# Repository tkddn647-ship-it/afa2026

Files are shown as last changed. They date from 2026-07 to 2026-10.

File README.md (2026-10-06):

# AFA2026 계측 시스템

학생 포뮬러 전기차(아주대학교 A-FA)의 **실차 데이터 계측 시스템**입니다.
서스펜션·가속도·인버터/BMS·조향 데이터를 STM32 한 곳에서 같은 시간축으로 모으고, Raspberry Pi를 거쳐 서버에 기록·실시간 표시·카메라 녹화까지 연결합니다.

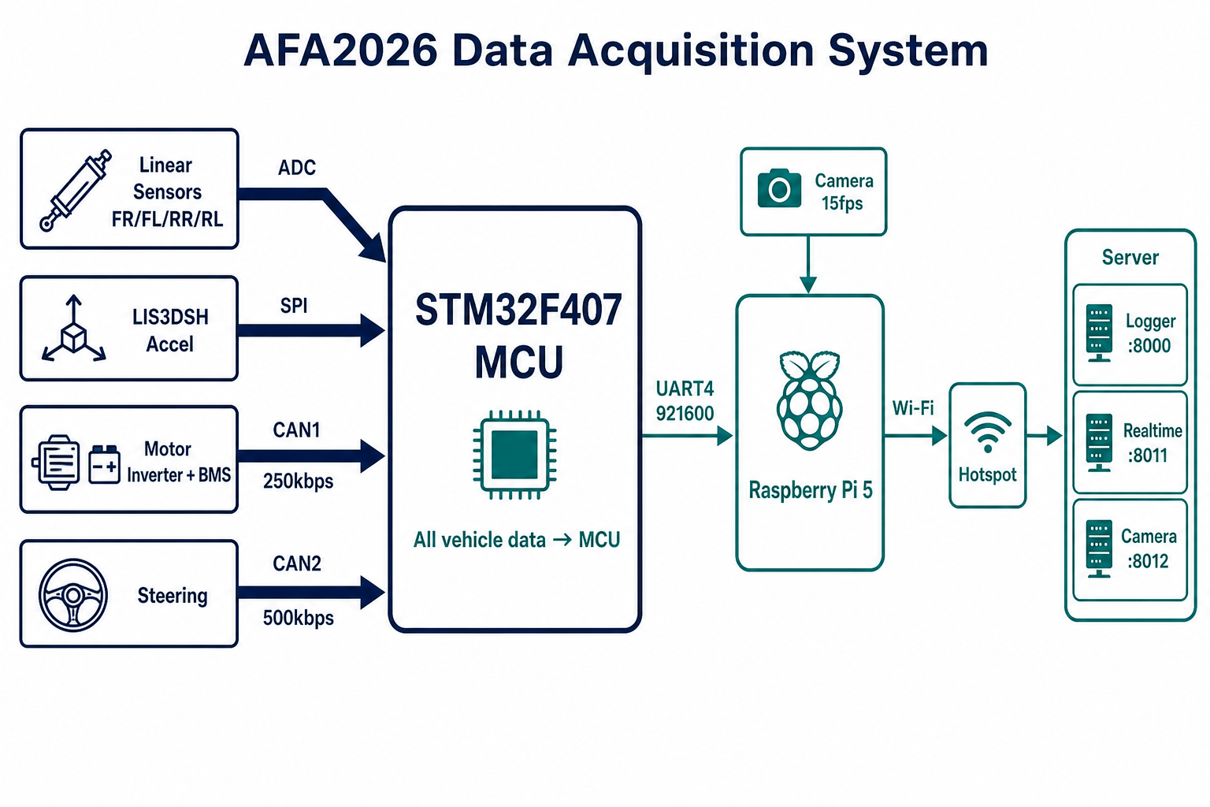
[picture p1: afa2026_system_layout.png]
AFA2026 Data Acquisition System


| 항목 | 내용 |
|---|---|
| 기간 | 2025.09 ~ 2026.08 |
| 역할 | 계측 파트장 (계측 파트 2인) |
| 하드웨어 | STM32F407, Raspberry Pi 5, Cascadia 인버터 · Orion BMS 2 · Bosch LWS (CAN) |
| 소프트웨어 | C (STM32 HAL, DMA), Python (FastAPI 서버, 분석), JavaScript (대시보드) |

## 주요 결과

| 항목 | 결과 |
|---|---|
| 데이터 운용 주기 | 전송 방식을 WebSocket → UDP/TCP로 바꾸고 MCU에 링버퍼 + DMA 적용, **10 Hz → 100 Hz** |
| 신호 오류 판정 | 실주행 로그 3개(74,062행)에서 인버터 DC 전류가 팩 전류보다 약 25% 크게 기록된 것을 발견, 비율 0.80 재현으로 **CAN 스케일 계수 누락** 규명, 보정 계수 1.25 도출 |
| 계측 정확도 | 섀시 다이나모 교차 검증: 최고속도 계측 90 km/h vs 다이나모 87 km/h (**오차 약 3.4%**) |
| EMI 대응 | HV 동작 시 튀는 센서 값을 HV ON/OFF 시점 대조로 전자기 간섭으로 규명, 신호선 분리 · 차폐로 해결 |
| 분석 도구 | 주행 로그와 카메라 영상을 같은 시간축으로 맞춰 보는 도구를 만들어 섀시 · 파워트레인 파트가 주행 분석에 사용 |

## 남은 과제

- **데이터 무결성**: 로그별 샘플 누락 5~10%, 깨진 행 최대 약 0.1% → 바이너리 패킷 + CRC + 시퀀스 번호로 수신 즉시 판별
- **절대값 검증**: 두 전류의 비율은 맞췄지만 어느 쪽이 절대적으로 정확한지는 미검증 → 클램프 미터로 독립 측정
- **보안**: 팀 내부 전용이라 성능을 우선했음 → 열린 포트 최소화, SSH 키 인증, 방화벽 적용
- 펌웨어 RTOS 전환, 리니어 센서 전원 강하 원인 특정 (아래 §11, §4.2)

## 저장소 구성

| 경로 | 내용 |
|---|---|
| `device/ECU_test/` | STM32CubeIDE 프로젝트 (메인 MCU 펌웨어) |
| `device/raspberry pi 5/` | UART 수신 · 서버 전송 · 카메라 업로드 |
| `server/` | 로깅(`udp_logger`), 실시간 대시보드(`udp_realtime`), 분석 서버(`analysis_server`) |
| `hardware/26_TELEPCB/` | 텔레메트리 보드 KiCad 회로도 · PCB · 거버 |

아래부터는 다음 담당자를 위한 **설계 의도와 구현 구조** 문서입니다.

---

## 1. 한 줄 요약

> 차량의 리니어·가속도·인버터/BMS·조향 데이터를 **MCU에서 동일 타임라인으로 통합 수집(100 Hz)** 하고, UART로 Raspberry Pi에 넘겨 Hotspot Wi‑Fi로 서버에 로깅·실시간 표시·카메라 녹화까지 연결한다.  
> (현재 구현 보드는 STM32F407이며, **시간 동기화가 목적이라 Teensy 등 다른 MCU로 대체 가능** — 자세한 내용은 §5.2)

---

## 2. 전체 시스템 구조

```
[차량 센서/ECU들]                    [현장 보드]                         [네트워크]         [서버]
Linear FR/FL/RR/RL ──ADC──┐
LIS3DSH Accel ──────SPI───┤
Motor Inverter+BMS ─CAN1──┼──▶ STM32F407 MCU ──UART4 921600──▶ Raspberry Pi 5 ──Wi‑Fi──▶ Hotspot
Steering (LWS) ─────CAN2──┘         ▲                              │ Camera 15fps              │
Wheel speed (옵션) ─USART2─┘         │                              │                           ▼
                                      │                         data_send_server.py     Logger   :8000
                                      └─ 모든 텔레메트리 1차 집약                         Realtime :8011
                                                                                         Camera   :8012
```

설계의 핵심은 **“모든 차량 데이터는 먼저 MCU로 모인다”** 입니다.

| 구간 | 역할 |
|---|---|
| 센서 / CAN | 물리량·차량 버스 데이터 생성 |
| **STM32 MCU** | 샘플링·단위 환산·버퍼링·동기 타임스탬프 |
| **UART4** | MCU → Pi 단일 CSV 스트림 |
| **Raspberry Pi 5** | 파싱, 배치 HTTP 전송, 카메라 프레임 업로드 |
| **Hotspot** | 이동 환경 Wi‑Fi (아이폰 핫스팟 등으로 운용) |
| **서버** | 집 노트북에서 구동. CSV 로깅, 실시간 대시보드, 카메라 수신/녹화. 공유기 포트포워딩 + SSH로 원격 관리 |

배치도 이미지: [`afa2026_system_layout.png`](./afa2026_system_layout.png)

서버는 클라우드 전용 VM이 아니라 **집에 둔 노트북**을 서버로 쓰고, 공유기·방화벽·SSH를 열어 **밖에서도 본인 PC로 원격 접속·제어**하는 방식으로 운용했습니다. 자세한 절차는 [§8. 집 서버 원격 접속 (포트포워딩 + SSH)](#8-집-서버-원격-접속-포트포워딩--ssh) 참고.

---

## 3. 하드웨어 설계

### 3.1 MCU 보드

| 항목 | 내용 |
|---|---|
| MCU | **STM32F407** (Discovery / 커스텀 PCB 연동) |
| 클럭 | HSE 크리스털 → PLL (시스템 클럭). UART/CAN 비트 타이밍 정확도에 필요 |
| 워치독 | IWDG (~1 s) — 메인 루프 정지 시 리셋 |

### 3.2 센서·버스 핀맵 (펌웨어 기준)

#### 리니어 포텐셔미터 (서스펜션 변위)

| 채널 | MCU 핀 | ADC | 비고 |
|---|---|-----|---|
| **FR** | PA1 | ADC1_IN1 | 3선: VCC / GND / Signal |
| **RR** | PA2 | ADC1_IN2 | |
| **RL** | PA3 | ADC1_IN3 | |
| **FL** | PA4 | ADC1_IN4 | |

- ADC 기준(VDDA)은 **3.3 V**
- 센서 공급/풀스케일 전압은 채널별로 다르며, **소프트웨어 vmax 캘리브레이션**으로 0–100 mm에 맞춤
- Discovery **PA0**은 유저 버튼용이라 리니어에 사용하지 않음

#### 가속도

| 센서 | 인터페이스 | 비고 |
|---|---|---|
| LIS3DSH | SPI1 | ODR 상향(400 Hz급)으로 200/100 Hz 샘플에 대응 |

#### CAN

| 버스 | 속도 | 핀 (펌웨어) | 상대 |
|---|---|---|---|
| **CAN1** | 250 kbps | **PB8 RX / PB9 TX** | Cascadia 인버터 + Orion BMS |
| **CAN2** | 500 kbps | **PB12 / PB13** | Bosch LWS 조향 |

> 회로도/PCB와 핀이 어긋나면(예: CAN1이 PA11/PA12로만 배선) 수신이 안 됩니다. 펌웨어는 **PB8/PB9, PB12/PB13** 기준입니다.

#### UART

| 포트 | 보드레이트 | 핀 | 용도 |
|---|---|-----|---|
| **UART4** | **921600** | PC10 TX / PC11 RX | Raspberry Pi 텔레메트리 |
| USART2 | 115200 | (휠스피드 아두이노 등) | 옵션 |

Pi 배선 (GPIO):

| STM32 | Raspberry Pi 5 |
|---|---|
| PC10 (UART4 TX) | Pin 10 (GPIO15 RX) |
| PC11 (UART4 RX) | Pin 8 (GPIO14 TX) |
| GND | GND |

포트: `/dev/ttyAMA0` (`dtparam=uart0=on`)

### 3.3 전원·배치·실차 이슈 (설계 시 고려)

- MCU·Pi는 근거리(배전함 등)에 두고, 모터컨트롤러는 함 밖인 경우가 많음 → **UART 거리는 짧아 유리**, 다만 **고전류 GND/EMI**가 케이블로 타고 들어옴
- 리니어 케이블에서 **신호↔파워 교차/단락** 시 중간 위치에서도 ADC가 ~3.3 V(100 mm 고정)처럼 보임 → 하드웨어 배선 문제로 확인됨
- 플로팅 ADC 핀은 센서 미연결 시에도 중간값이 움직임 → 정상 현상
- 핫스팟 + 차량 이동 시 **Pi→서버 업로드**가 병목이 되어 로그 유효 Hz가 떨어질 수 있음 (MCU 샘플링과 별개)

---

## 4. 소프트웨어 아키텍처 (device)

### 4.1 디렉터리

```
device/
├── ECU_test/                 # STM32CubeIDE 프로젝트 (메인 MCU 펌웨어)
│   ├── Core/Inc|Src/         # 애플리케이션 코드
│   ├── Drivers/              # HAL / CMSIS
│   └── ECU_test.ioc          # CubeMX 설정
├── raspberry pi 5/           # Pi 수신·서버 전송·카메라
│   ├── Uart_stm.py           # UART CSV 파서
│   ├── data_send_server.py   # ingest / realtime 전송
│   ├── camera.py             # 카메라 프레임 업로드 (15fps 운용)
│   └── stm_ingest.env.example
├── wheel_speed/              # 휠스피드 아두이노 (옵션)
├── Fluid_Sensor/             # 유체 센서 스케치
├── esp32/ , esp32_motor_can/ # 보조/실험용
└── ...
```

### 4.2 STM32 펌웨어 — 슈퍼루프 설계

RTOS 없이 **메인 루프 + 논블로킹** 구조입니다 (`main.c`).

1. `MX_*_Init` — GPIO, CAN1/2, UART, ADC, SPI, DMA
2. `LIS3DSH` / `CAN_Vehicle` / `CAN_LWS` / `SensorUart` / `Uart4Tx` 초기화
3. 루프:
   - CAN FIFO 드레인·파싱
   - `SensorUart_Process()` — 100 Hz 샘플 적재, 20 Hz DMA flush
   - IWDG kick

#### 샘플링 / 전송

| 항목 | 값 | 파일 |
|---|-----|---|
| 샘플 주기 | **10 ms (100 Hz)** | `sensor_uart.h` / `.c` |
| UART flush | **20 Hz**, 배치 5샘플 | 동일 |
| TX | UART4 **DMA 논블로킹** | `uart4_tx.c` |
| Baud | **921600** | `usart.c` |

초기에는 200 Hz(5 ms)였으나, 실차·무선 부하를 고려해 **100 Hz**로 조정했습니다.

#### 리니어 ADC 처리 (`adc.c` / `adc.h`)

1. 채널당 **8회 평균**
2. **EMA** 필터 (노이즈 완화)
3. 전압 환산: `voltage_mv = raw × 3300 / 4095`
4. 위치 환산(채널별):

```text
position_mm = (voltage_mv / ADC_LINEAR_VMAX_xx_MV) × 100
```

풀 스트로크 실측으로 vmax를 맞춥니다. (예: 풀에서 88.6 mm가 나오면 `vmax_new = vmax_old × 0.886`)

최신 캘리 상수 예:

| 채널 | `ADC_LINEAR_VMAX_*_MV` |
|---|---|
| FR | 1825 |
| RR | 1835 |
| RL | 1827 |
| FL | 1818 |

미해결 이슈 — ADC형 센서 전원 강하 원인 규명 필요: 리니어 포텐셔미터 전원부에서 3A 레귤레이터 Vout 자체는 3.3V로 정상이었으나, PCB를 지나 센서 커넥터 단에서는 2.3~2.7V까지 떨어지는 현상이 실측됐습니다. 흐르는 전류가 mA 수준(저항 분압 구조)인 점을 감안하면 컨버터 용량 부족은 아니며, Vout 이후 구간(PCB 파워 트레이스 또는 커넥터 접점)에서 비정상적으로 큰 저항이 있는 것으로 추정되는데 이게 어디가 문제인지 정확하게 확인을 못해서 소프트웨어적으로 캘리브레이션 우선 했습니다. 이 전압 강하가 vmax 캘리브레이션을 흔드는 원인이 될 수 있어, 트레이스 문제인지 커넥터 접점 문제인지 다음 담당자가 실측으로 특정해야 하는 미해결 문제입니다.

#### CAN 파싱 (`can_vehicle.c`, `can_lws.c`)

- Cascadia Motion 프로토콜(V5.9 계열): 온도·전류·전압·토크·Id/Iq·RPM 등 **int16 × 0.1** 환산 후 float 보관
- Orion BMS 커스텀 ID(0x081/0x082 등): 전압·전류·Ah·온도·CCL/DCL
- LWS: 조향각·조향 속도
- UART로 나가기 전에 **이미 공학 단위로 환산**됨 (Pi/서버에서 재스케일하지 않음)
- `can1` / `can2`: 최근 **500 ms** 내 수신 여부 (0/1)

#### UART CSV 한 줄 (순서 고정)

```text
stm_ms, FR, FL, RR, RL, x_g, y_g, z_g, ecu_temp,
steering_angle, steering_speed,
inv_temp_igt, inv_temp_motor, inv_motor_speed, inv_dc_current, inv_voltage,
motor_precharge, motor_main_contactor, motor_inverter_mode,
inv_shudder_torque, inv_id_feedback, inv_iq_feedback,
inv_torque_commanded, inv_torque_feedback, inv_id_command, inv_iq_command,
bms_charge, bms_voltage, bms_current, bms_ccl, bms_dcl, bms_temp_maxvalue, bms_capacity,
can1, can2
```

제어 라인(데이터 아님): `STM_READY`, `HB,...`, `LWS_CAL,...`

차속은 `inv_motor_speed × 0.0222328` (타이어 외경 460 mm, 감속비 3.9)로 **서버/Pi에서 계산**하는 것을 권장 (UART 필드 추가 불필요).

### 4.3 Raspberry Pi 5

| 스크립트 | 역할 |
|---|---|
| `Uart_stm.py` | 921600 수신, CSV 파싱, 100 Hz/20 Hz 배치 개념 |
| `data_send_server.py` | 배치를 Logger `:8000/ingest` + (옵션) Realtime `:8011` 로 POST |
| `camera.py` | JPEG 프레임 업로드 (운용 **15 fps**) |
| `uart_test.py` | 보드레이트/배선 점검 |

예시:

```bash
python3 data_send_server.py \
  --port /dev/ttyAMA0 \
  --baud 921600 \
  --realtime-url http://<server>:8011/api/live/ingest
```

환경 변수 예시는 `stm_ingest.env.example` 참고.

### 4.4 서버 쪽 (연동만 요약)

| 서비스 | 포트 | 역할 |
|---|---|---|
| `udp_logger` | 8000 | CSV 로깅 ingest |
| `udp_realtime` | 8011 | 실시간 대시보드 |
| camera | 8012 | 프레임 수신·녹화(ffmpeg) |

실차에서 로그 유효 Hz가 50대까지 떨어지는 경우, CSV의 `stm_ms`는 대부분 10 ms를 유지하는 반면 wall-clock 초당 행 수만 줄어든 패턴이 많았습니다 → **MCU 샘플링보다 Hotspot/서버 업로드·카메라 부하**가 원인인 경우가 많습니다. 센서 100 Hz를 유지하려면 카메라 fps/해상도를 먼저 낮추는 편이 유리합니다.

---

## 5. 핵심 설계 판단

### 5.1 MCU 중앙 통합 — 핵심은 “시간 동기화”

이 프로젝트에서 MCU(현재 구현은 STM32F407)를 둔 **가장 큰 이유**는 브랜드가 아니라 **시간 동기화**입니다.

- 리니어·가속도·인버터/BMS CAN·조향 CAN을 **서로 다른 장치·주기**로 받으면, 나중에 맞춰도 샘플 시각이 어긋나기 쉽습니다.
- 그래서 **한 MCU의 틱(`stm_ms` / `HAL_GetTick` 계열)으로 모든 채널을 같은 타임라인에 찍어** Pi·서버로 넘기는 구조를 택했습니다.
- Pi는 네트워크·카메라·업로드를 담당하고, **정밀 주기 샘플링·CAN 집약은 MCU**에 두는 역할 분리입니다.

| | 내용 |
|--|---|
| **선택 이유** | 서스펜션·구동·조향을 **동일 타임스탬프**로 맞춤 |
| **장점** | 단일 UART 스트림, 디버그·확장 용이, 실차 EMI 환경에서도 샘플 주기를 MCU가 책임 |
| **리스크** | MCU/UART가 단일 장애점, CSV가 길면 UART·무선 부하 증가 |

### 5.2 STM32를 꼭 고집할 필요는 없음

**“STM이어야만 한다”는 제약은 없습니다.**  
필요한 것은 대략 다음을 만족하는 **실시간 MCU**면 됩니다.

- ADC(리니어) + (가능하면) SPI/I2C 센서
- CAN 1~2채널 (인버터/BMS/조향)
- 안정적인 주기 타이머·타임스탬프
- Pi로 넘길 UART(또는 USB serial 등) 고속 스트림

그래서 예를 들면 아래도 **같은 역할의 중앙 계측 MCU**로 대체·재구현 가능합니다.

| 후보 | 메모 |
|---|---|
| **Teensy** (4.x 등) | 고속 클럭, USB/시리얼 편함, 커뮤니티 센서 예제 많음 |
| **다른 STM32** | 핀맵·Cube 설정만 맞으면 현재 구조와 가장 유사 |
| **ESP32** 계열 | Wi‑Fi 내장이라 Pi를 줄이는 실험도 가능하나, CAN·실시간·EMI는 설계 부담이 달라짐 |
| **기타 Cortex‑M / 보드** | ADC+CAN+UART만 되면 파이프라인 개념은 동일 |

지금 저장소 펌웨어는 **STM32F407 Discovery/Cube 기반**으로 작성된 **한 가지 구현**입니다.  
구조(센서·CAN → MCU 타임라인 → 시리얼 → Pi → 서버)만 유지하면 **Teensy 등 다른 MCU로 포팅해도 설계 의도는 그대로**입니다.

### 5.3 대안이었던 분산 전송

- 센서·카메라를 각자 올리거나 주기만 다르게 하는 방식
- 무선 부하는 나눌 수 있으나 **시각 동기·배선·프로토콜 복잡도**가 커짐 → 본 프로젝트 목표(동기 로깅)와는 덜 맞음

### 5.4 샘플링 100 Hz / UART 921600

- 200 Hz → 100 Hz: 루프·UART·업로드 여유
- 460800 ↔ 921600: 용량 vs EMI/배선 안정성 트레이드오프. 근거리면 921600 가능

### 5.5 리니어 캘리브레이션을 소프트웨어로

- 채널마다 풀전압이 다름 (하드웨어·케이블·장착)
- 코드에서 채널별 `vmax`로 100 mm 맞춤 — **배선 불량(신호/파워 교차)은 캘리로 고칠 수 없음**

### 5.6 텔레메트리 전송 방식의 다른 선택지

계측에서 “차 → 기록 PC/서버”로 데이터를 넘기는 방법은 팀이 제각각이라, **이 저장소 방식(MCU + Pi + Hotspot Wi‑Fi)이 유일한 정답은 아닙니다.**  
크게 보면 아래 세 갈래로 나뉩니다.

#### (A) 상용 데이터로거를 사서 쓰는 경우

- 완성품 로거에 센서/CAN을 꽂고 USB·자체 소프트웨어로 기록
- **장점:** 배선·펌웨어·동기 UI가 제품에 포함되어 있어 구현 부담이 작음
- **단점:** 가격, 커스텀 필드/서버 연동·실시간 웹 파이프라인은 제품 제약을 따름
- DIY 계측을 깊게 파고든 팀을 찾기 어려운 이유 중 하나가, **많은 팀이 이 경로로 가기 때문**입니다. 상용 로거 사용 자체는 문제 없고, 다만 **자작 MCU 파이프라인 노하우를 물어볼 상대는 상대적으로 적습니다.**

#### (B) 본 프로젝트 — MCU 집약 + Pi + Hotspot(Wi‑Fi/인터넷)

- MCU가 동기 샘플 → UART → Pi → Hotspot → 집 서버
- **장점:** 필드·서버·카메라를 자유롭게 확장, 비용 대비 커스터마이즈
- **단점:** 무선은 Hotspot/공유기 품질에 민감, 직접 디버깅·보안·전원 설계가 필요

#### (C) UART형 장거리 무선 모듈 — 예: **EBYTE E220-900T22S**

일부 팀은 Wi‑Fi/휴대폰 핫스팟 대신, MCU(또는 중간 보드)의 **UART에 LoRa 계열 무선 시리얼 모듈**을 달아 송수신합니다.

| 항목 | E220-900T22S 요약 ([Ebyte 제품 페이지](https://www.cdebyte.com/products/E220-900T22S)) |
|---|---|
| 종류 | LoRa 기반 **무선 시리얼(UART) 모듈** (LLCC68) |
| 주파수 | 약 **850.125 ~ 930.125 MHz** (기본 예: 873.125 MHz, 868/915 MHz 대역 운용) |
| 출력 | 최대 **22 dBm** |
| 공칭 거리 | 개활지 기준 **수 km**급 (안테나·속도·환경에 크게 좌우) |
| 공중 전송률 | 대략 **2.4 kbps ~ 62.5 kbps** (설정에 따라) — **Wi‑Fi보다 훨씬 느림** |
| 인터페이스 | TTL UART (3.3 V 로직), MCU 시리얼에 붙이는 형태 |

**어떻게 쓰이나 (개념):**

```text
[차량 MCU] --UART--> [E220 송신]  ~~~900MHz LoRa~~~  [E220 수신] --UART--> [기록 PC / 다른 MCU]
```

- Hotspot·공유기·인터넷 없이도 **차 ↔ 피트/노트북** 직통에 가깝게 쓸 수 있는 선택지
- 다만 공중 속도가 낮아 **본 프로젝트처럼 긴 CSV를 100 Hz로 풀 스트리밍**하기엔 대역이 부족할 수 있음  
  → 보통은 **샘플 주기·필드 축소, 배치/압축, 또는 로컬 SD에 풀레이트 저장 + 무선은 요약/저속** 같은 설계가 필요
- 주파수·출력은 **해당 국가 전파 규정**을 반드시 확인할 것 (무단 고출력·비허가 대역 사용 금지)

본 저장소는 **(B) Wi‑Fi/Hotspot 경로를 구현·문서화**한 것이며, **(C) E220-900T22S 같은 UART LoRa 모듈 통신도 업계·동계에서 쓰이는 다른 갈래**라는 점만 참고용으로 남깁니다.  
이 레포에 E220 드라이버/설정 코드는 포함되어 있지 않습니다.

---

## 6. 디버그 체크리스트

### STM Live Expressions 예

```text
adc_linear_readings[0..3]   // FR,RR,RL,FL
adc_debug_raw[i]
g_can_vehicle_state.rx_total
g_lws_state.rx_count
uart4_tx_overflow
sensor_uart_overflow
main_loop_count
```

### 증상별

| 증상 | 우선 의심 |
|---|---|
| ADC만 나오고 CAN 0 | CAN 배선/트랜시버/핀맵, `can1`/`can2` |
| 중간인데 리니어 100 고정, raw≈4095 | 신호선–VCC 단락/교차 |
| 미연결 채널 값이 튐 | 플로팅 핀 (정상) |
| 로그 Hz만 떨어짐, `stm_ms`는 ~10 ms | Pi→서버 Wi‑Fi / 카메라 부하 |
| -553 mm 등 이상값 다수 | UART 줄 깨짐·컬럼 밀림 |

---

## 7. 빌드·플래시·실행

### STM32

1. STM32CubeIDE에서 `device/ECU_test` 오픈
2. Build → Debug/Run으로 보드에 플래시
3. UART4 921600, CAN 핀맵이 배선과 일치하는지 확인

### Raspberry Pi

```bash
cd "device/raspberry pi 5"
pip install pyserial requests
python3 data_send_server.py --port /dev/ttyAMA0 --baud 921600
```

카메라:

```bash
python3 camera.py --fps 15
```

---

## 8. 집 서버 원격 접속 (포트포워딩 + SSH)

계측 서버(`udp_logger` / `udp_realtime` / camera 등)는 **집 PC(노트북)** 에서 돌리고, 현장(차·Pi)은 Hotspot Wi‑Fi로 그 서버에 데이터를 올립니다.  
서버 노트북은 항상 옆에 둘 수 없으므로, **집 공유기 포트포워딩 + OS 방화벽에서 SSH(22) 허용**해 두고, 밖에서는 **공인 IP 또는 DDNS 도메인**으로 SSH 접속해 노트북을 원격 제어했습니다.

### 8.1 전체 흐름

```text
[밖: 본인 노트북 / 폰]
        │  ssh user@<공인IP또는도메인> -p 22
        ▼
[인터넷]
        ▼
[집 공유기]  ── 포트포워딩: 외부 22 → 서버노트북 사설IP:22
        │         (필요 시 8000/8011/8012 등 HTTP도 포워딩)
        ▼
[서버 노트북]  OpenSSH 서버 수신
        │
        ├─ 터미널로 서비스 재시작, 로그 확인, 코드 pull …
        └─ (터널/브라우저) 로거·실시간 페이지 점검
```

즉 **“서버 = 집 노트북”** 이고, **“원격 = SSH로 그 노트북에 들어가 조작”** 입니다.

### 8.2 서버 노트북 준비 (SSH 서버)

1. OS에 **OpenSSH Server** 설치·활성화  
   - Linux: `openssh-server` 설치 후 `sshd` 기동  
   - Windows: 선택적 기능에서 OpenSSH 서버 사용 가능
2. 로그인할 **계정/비밀번호 또는 SSH 키** 준비 (키 인증 권장)
3. 노트북이 절전으로 네트워크가 끊기지 않게 **절전/디스플레이 끄기 설정** 조정
4. 가능하면 공유기 DHCP에서 서버 PC에 **고정 사설 IP** (예: `192.168.0.50`) 예약

접속 예:

```bash
ssh <username>@<공인IP또는도메인>
# 포트가 22가 아니면
ssh -p <포트> <username>@<공인IP또는도메인>
```

접속되면 집 노트북 셸이 열리고, 여기서 `server/` 서비스 기동·재시작·로그 확인 등 **원격으로 서버를 조종**할 수 있습니다.

### 8.3 OS 방화벽 — 22번(SSH) 허용

노트북 방화벽에서 **인바운드 TCP 22** 를 허용해야 공유기까지 들어온 SSH가 PC에 도달합니다.

- Linux (`ufw` 예): `sudo ufw allow 22/tcp` 후 `sudo ufw enable`
- Windows: Windows Defender 방화벽 → 인바운드 규칙에서 OpenSSH(또는 TCP 22) 허용

계측 HTTP도 밖에서도 열려야 하면 동일하게 **8000 / 8011 / 8012** 등을 허용합니다.  
(현장 Pi → 서버만 쓰고, 본인은 SSH만 쓸 계획이면 HTTP는 LAN 전용으로 두고 SSH 터널로만 볼 수도 있습니다.)

### 8.4 집 공유기 포트포워딩

공유기 관리 페이지(보통 `192.168.0.1` / `192.168.1.1`)에서:

| 항목 | 설정 예 |
|---|---|
| 서비스 이름 | SSH |
| 외부(WAN) 포트 | **22** (또는 보안상 다른 포트로 바꿔 내부 22로 변환) |
| 내부 IP | 서버 노트북 사설 IP |
| 내부 포트 | **22** |
| 프로토콜 | TCP |

추가로 로거/실시간/카메라를 외부에서 직접 열려면:

| 외부 포트 | 내부 | 용도 |
|---|---|---|
| 8000 | 노트북:8000 | Logger ingest / CSV |
| 8011 | 노트북:8011 | Realtime |
| 8012 | 노트북:8012 | Camera |

Pi의 `--url` / `--realtime-url` 에는 **공유기 공인 IP 또는 DDNS 도메인**을 넣습니다.  
예: `http://<your-domain>.ddns.net:8000/ingest`

### 8.5 공인 IP vs 도메인 (DDNS)

- **고정 공인 IP**면 IP로 바로 `ssh user@x.x.x.x`
- 가정용 회선은 IP가 자주 바뀌므로 **DDNS 도메인**(공유기 내장 DDNS 또는 외부 DDNS)을 묶어 두는 편이 편함  
  → 현장·원격 모두 `도메인:포트`로 접속·ingest

Pi/노트북이 Hotspot에 있어도, **목적지가 집 공인 IP/도메인**이면 인터넷 경유로 집 서버에 도달합니다.

### 8.6 실제로 한 일 (운용)

1. 집 노트북에 서버 스택 실행 (`start_servers.sh` 등)
2. 공유기에서 **22 → 노트북**, 필요 시 **8000/8011/8012** 포워딩
3. 노트북 방화벽에서 해당 포트 허용
4. 밖(또는 차 근처)에서 **SSH로 집 노트북 접속** → 서비스 상태 확인, 재시작, 설정 수정
5. 현장 Pi는 Hotspot으로 인터넷 올린 뒤, **도메인/공인 IP의 ingest URL**로 데이터·카메라 전송

이 구성으로 **서버 노트북을 집에 둔 채 원격으로 제어**하며 계측 파이프라인을 유지했습니다.

### 8.7 보안 주의 (필수)

- SSH를 인터넷에 열면 **무차별 대입 공격** 대상이 됩니다.
  - 가능하면 **키 인증만** 허용, 비밀번호 로그인 비활성
  - 외부 SSH 포트를 22 대신 **임의 포트**로 포워딩
  - `fail2ban` 등 차단, 강한 비밀번호/키 사용
- 공유기·PC 관리자 비밀번호를 기본값으로 두지 말 것
- README/깃에 **실제 공인 IP·계정·비밀번호·개인 도메인 크리덴셜을 올리지 말 것**
- 장기간 안 쓰면 포워딩·방화벽 규칙을 끄는 것을 권장

---

## 9. 라이선스 / 주의

- STM HAL/CMSIS는 ST 라이선스 조건을 따릅니다.
- `.env` / 실제 ingest URL·자격 증명은 커밋하지 마세요. `*.env.example`만 사용하세요.
- `Debug/` 빌드 산출물, `__pycache__`, 셸 히스토리는 저장소에서 제외하는 것을 권장합니다.
- 집 서버 SSH/포트포워딩은 편리하지만 노출면이 생기므로 [§8.7](#87-보안-주의-필수)을 지키세요.

---

## 10. 변경 이력 (device 관점 요약)

- STM32 슈퍼루프 + CAN1/2 파싱 + UART CSV 파이프라인
- 리니어 ADC  Averaging/EMA + 채널별 vmax 캘리
- UART DMA TX, baud 921600, 샘플 100 Hz / flush 20 Hz
- Pi `Uart_stm` / `data_send_server` / 카메라 연동
- `can1`/`can2` 링크 플래그, 인버터 토크·Id/Iq 필드 확장
- 실차 EMI·케이블·핫스팟 병목 경험을 반영한 운용 가이드
- 집 노트북 서버 + 공유기 포트포워딩 + SSH(22) 원격 제어 운용 문서화
- MCU 채택 이유(시간 동기화) 명시, STM 외 Teensy 등 대체 가능 안내
- 텔레메트리 대안: 상용 로거 / Wi‑Fi·Hotspot / EBYTE E220-900T22S(UART LoRa) 비교 정리

## 11. 아쉬운점
RTOS 미적용 — 시간 부족으로 남은 아쉬운 점
현재 펌웨어는 RTOS 없이 메인 루프 + DMA/인터럽트 구조입니다. CAN 수신, UART 송신 등 타이밍이 중요한 부분은 이미 DMA·인터럽트로 처리되고 있어서, RTOS가 없다고 해서 당장 샘플링 타이밍이 깨지는 구조는 아닙니다.
다만 기능이 하나씩 늘어나면서 메인 루프 안에 로직이 계속 쌓이는 구조가 됐고, 시간이 있었다면 FreeRTOS 등으로 태스크를 나눠서(센서 샘플링 태스크, CAN 파싱 태스크, UART 송신 태스크 등) 더 깔끔하게 모듈화하고 싶었던 부분입니다. 단순히 시간이 부족해서 모듈화 리팩터링까지 못 간 것이 아쉽습니다.

하드웨어 모듈화 - 시간 부족
실제 계측 장비(데이터로거)처럼 만들고싶었지만, 시간문제와 당시 지식이 조금 모자랐기에 장비화(?)는 못했습니다... 실제로 시중에 파는 계측장비처럼 제작이 가능하다면 진짜 가능할 것 같긴한데 아무튼 가능하다면 매번 안바꿔도 되는 부분이라 이거 성공하면 진짜 히트입니다.

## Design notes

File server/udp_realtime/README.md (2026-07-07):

# udp_realtime

기존 `/home/ubuntu/udp_logger/app.py`와 분리된 독립 실시간 서버입니다.

실행:

```bash
cd /home/ubuntu/udp_realtime
uvicorn realtime_server:app --host 0.0.0.0 --port 8011
```

기존 로깅 서버에서 이 서버로 포워딩하려면:

```bash
cd /home/ubuntu/udp_logger
FORWARD_URL=http://127.0.0.1:8011/api/live/ingest uvicorn app:app --host 0.0.0.0 --port 8010
```

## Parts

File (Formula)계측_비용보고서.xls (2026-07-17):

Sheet: 종합
대학생 자작자동차대회 비용보고서(원가명세표)
엔트리 |  | 0
학교명 |  | 아주대학교
팀 명 |  | A-FA
차량제작비 |  | #REF!
연번 | 구분 | 금액
1 | 엔진&구동시스템 | #REF!
2 | 조향시스템 | #REF!
3 | 현가시스템 | #REF!
4 | 제동시스템 | ₩4840
5 | 프레임&바디 | #REF!
6 | 전장시스템 | ₩2080136
7 | 휠&타이어 | #REF!
8 | 기타 | #REF!
 | 차량제작비 합계 | #REF!
** 원가명세표 시트에서 자동 계산된 결과입니다.
** 원가명세표 시트만 작성하시면 됩니다.
** 원가명세표는 팀의 현실적인 비용관리가 최우선 입니다.
1) '제품명, 구매-가공처' 항목은 다음 차량 제작 시 참고가 목적
2) 구매품, 가공품(부품-재료비, 외주 가공비)에 한해 기입 (기타 용접, 커팅, 노동비 등 제외)
3) 기존 사용 물품 또는 스폰서 물품의 경우 현재 시세가격으로 기입
4) 볼트, 너트, 밴드 등은 적용된 시스템에 기입 (중점 점검 항목)
5) 케이블타이, 절연 테이프 등은 제외
** 원가명세표 예시 참조

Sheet: 원가명세표
대학생 자작자동차대회 비용보고서(원가명세표) |  |  |  |  |  |  | 엔트리 |  | 학교명 | 아주대학교 | 기입 항목 | 수정 금지
 |  |  |  |  |  |  | 팀 명 | A-FA | 차량제작비 | #REF!
연번 | 구분 | Assy |  | 제품명 | 구매, 가공처 | 부품, 재료비 | 외주 가공비 | 단가 | 수량 | 합계
1 | 전장시스템 | TELEMETRY BOX | STM32보드 | STM32F4DISCOVERY | 디바이스 마트 | ₩59400 | ₩0 | ₩59400 | 1 | ₩59400
2 | 전장시스템 |  | 카메라 | Raspberry Pi Camera Module 3 Wide | 디바이스 마트 | ₩53900 | ₩0 | ₩53900 | 1 | ₩53900
3 | 전장시스템 |  | 라즈베리파이 보드 | Raspberry pi 5 | 아이씨뱅큐 | ₩319000 | ₩0 | ₩319000 | 1 | ₩319000
4 | 전장시스템 |  | Linear Sensor | Haltech Linear Position sensor | 투인스 컴퍼니 | ₩280100 | ₩0 | ₩280100 | 4 | ₩1120400
5 | 전장시스템 |  | 휠스피드 센서 | MOBIS 59810-A5300 | Hello Car | ₩15400 | ₩0 | ₩15400 | 2 | ₩30800
6 | 전장시스템 |  | ADXL345 | ADXL345 | 디바이스 마트 | ₩5280 | ₩0 | ₩5280 | 1 | ₩5280
7 | 전장시스템 |  | 스티어링 센서 | BOSCH LWS 7.3.6 | XTRA MOTORSPORTS | ₩281057 | ₩0 | ₩281057 | 1 | ₩281057
8 | 전장시스템 |  | CAN 트랜시버 | SN65HVD230 | 디바이스 마트 | ₩2200 | ₩0 | ₩2200 | 2 | ₩4400
9 | 전장시스템 |  | PCB 보드 | PCB | JLC PCB | ₩0 | ₩2811 | ₩2811 | 1 | ₩2811
10 | 전장시스템 |  | Arduino UNO R3 | Arduino UNO R3 | 디바이스 마트 | ₩31900 | ₩0 | ₩31900 | 1 | ₩31900
11 | 전장시스템 |  | 1k옴 저항 | CFR 1/4W 5% 1Kohm | 엘레파츠 | ₩10 | ₩0 | ₩10 | 5 | ₩50
12 | 전장시스템 |  | 10k옴 저항 | CFR 1/4W 5% 10Kohm | 엘레파츠 | ₩10 | ₩0 | ₩10 | 5 | ₩50
13 | 전장시스템 |  | 2.7k옴 저항 | CFR 1/4W 5% 2.7Kohm | 엘레파츠 | ₩10 | ₩0 | ₩10 | 2 | ₩20
14 | 전장시스템 |  | DCDC컨버터 | MP1584 | 디바이스 마트 | ₩2200 | ₩0 | ₩2200 | 4 | ₩8800
15 | 전장시스템 |  | 8핀 PCB 커넥터 (전력)(양) | MOLEX 5557-8P | 엘레파츠 | ₩306 | ₩0 | ₩306 | 5 | ₩1530
16 | 전장시스템 |  | 8핀 PCB 커넥터 (전력)(음) | MOLEX 5557-8P | 엘레파츠 | ₩306 | ₩0 | ₩306 | 5 | ₩1530
17 | 전장시스템 |  | 2핀 PCB 커넥터 (전력)(양) | MOLEX 5557-2P | 엘레파츠 | ₩306 | ₩0 | ₩306 | 4 | ₩1224
18 | 전장시스템 |  | 2핀 PCB 커넥터 (전력)(음) | MOLEX 5557-2P | 엘레파츠 | ₩306 | ₩0 | ₩306 | 4 | ₩1224
19 | 전장시스템 |  | 트랜지스터 | 2SC1815 | 디바이스 마트 | ₩50 | ₩0 | ₩50 | 5 | ₩250
20 | 전장시스템 |  | 계측 박스 고정용 볼트 | M4 | 대광볼트 | ₩20 | ₩0 | ₩20 | 2 | ₩40
21 | 전장시스템 |  | 계측 박스 고정용너트 | M4 | 대광볼트 | ₩20 | ₩0 | ₩20 | 2 | ₩40
22 | 전장시스템 |  | micro SD 카드 | SANDISK ULTRA SD 카드 | 쿠팡 | ₩20700 | ₩0 | ₩20700 | 1 | ₩20700
23 | 전장시스템 |  | 핀헤더 소켓 | 핀헤더 소켓 Dual 2x25 | 디바이스 마트 | ₩605 | ₩0 | ₩605 | 8 | ₩4840
24 | 전장시스템 |  | 박스 | BC-APT-162110 | 박스코 | ₩108890 | ₩0 | ₩108890 | 1 | ₩108890
25 | 전장시스템 |  | CSI-HDMI | Arducam CSI to HDMI Extension Module[B0091] | 디바이스 마트 | ₩22000 | ₩0 | ₩22000 | 1 | ₩22000
 |  |  | 합계 |  |  |  |  |  |  | ₩2080136
 |  |  | Total |  |  |  |  |  |  | #REF!
 |  |  |  |  |  |  |  |  |  | 한국자동차공학회 Copyright © KSAE

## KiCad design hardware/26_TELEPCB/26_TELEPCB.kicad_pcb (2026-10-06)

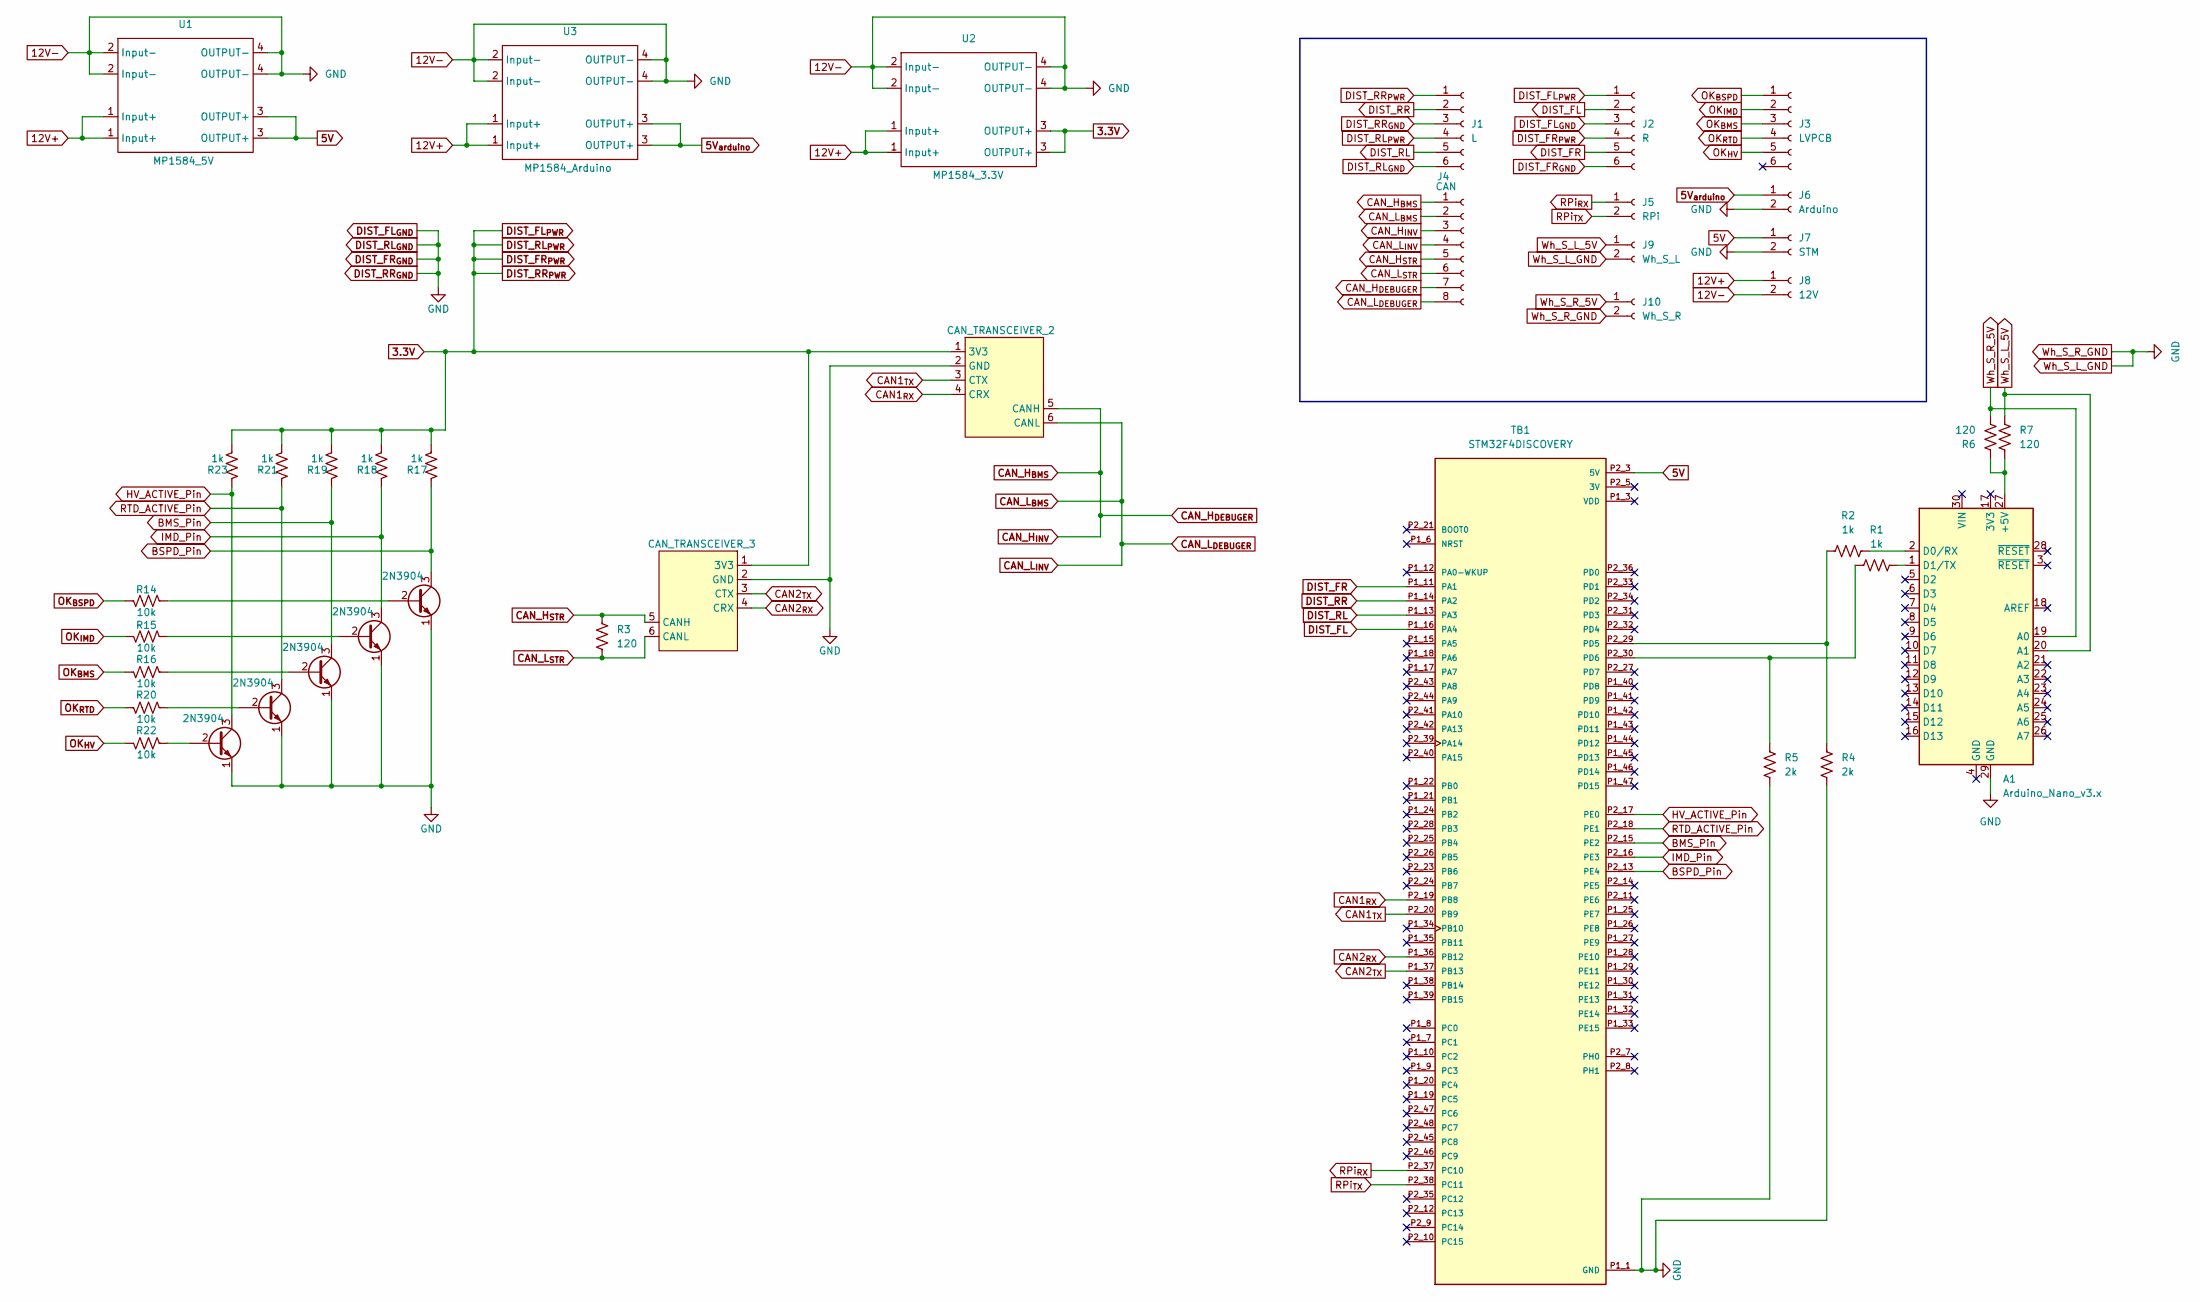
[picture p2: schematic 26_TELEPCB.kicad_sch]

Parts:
A1: Arduino_Nano_v3.x; Arduino_Nano
J1: L; Molex_SPOX_5267-06A_1x06_P2.50mm_Vertical
J2: R; Molex_SPOX_5267-06A_1x06_P2.50mm_Vertical
J3: LVPCB; Molex_SPOX_5267-06A_1x06_P2.50mm_Vertical
J4: CAN; Molex_SPOX_5267-08A_1x08_P2.50mm_Vertical
J5: RPi; Molex_Mini-Fit_Jr_5566-02A_2x01_P4.20mm_Vertical
J6: Arduino; Molex_Mini-Fit_Jr_5566-02A_2x01_P4.20mm_Vertical
J7: STM; Molex_Mini-Fit_Jr_5566-02A_2x01_P4.20mm_Vertical
J8: 12V; Molex_Mini-Fit_Jr_5566-02A_2x01_P4.20mm_Vertical
J9: Wh_S_L; Molex_Mini-Fit_Jr_5566-02A_2x01_P4.20mm_Vertical
J10: Wh_S_R; Molex_Mini-Fit_Jr_5566-02A_2x01_P4.20mm_Vertical
Q6, Q7, Q8, Q9, Q10: 2N3904; TO-92_Inline_Wide
R1, R2: 1k; R_Axial_DIN0207_L6.3mm_D2.5mm_P7.62mm_Horizontal
R3, R6, R7: 120; R_Axial_DIN0207_L6.3mm_D2.5mm_P7.62mm_Horizontal
R4, R5: 2k; R_Axial_DIN0207_L6.3mm_D2.5mm_P7.62mm_Horizontal
R14, R15, R16, R20, R22: 10k; R_1206_3216Metric_Pad1.30x1.75mm_HandSolder
R17, R18, R19, R21, R23: 1k; R_1206_3216Metric_Pad1.30x1.75mm_HandSolder
TB1: STM32F4DISCOVERY; MODULE_STM32F4DISCOVERY; PARTREV 6
U1: MP1584_5V; SRT_MPT1584EN_Module
U2: MP1584_3.3V; SRT_MPT1584EN_Module
U3: MP1584_Arduino; SRT_MPT1584EN_Module
U9: CAN_TRANSCEIVER_3; CAN_TRANSIVER
U11: CAN_TRANSCEIVER_2; CAN_TRANSIVER

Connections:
3.3V: J1.1, J1.4, J2.1, J2.4, R17.1, R18.1, R19.1, R21.1, R23.1, U2.3 (OUTPUT+), U9.1 (3V3), U11.1 (3V3)
5V: J7.1, TB1.P2_3 (5V), TB1.P2_4 (5V), U1.3 (OUTPUT+)
5V_{arduino}: J6.1, U3.3 (OUTPUT+)
12V+: J8.1, U1.1 (Input+), U2.1 (Input+), U3.1 (Input+)
12V-: A1.29 (GND), J1.3, J1.6, J2.3, J2.6, J6.2, J7.2, J8.2, J9.2, J10.2, Q6.1 (E), Q7.1 (E), Q8.1 (E), Q9.1 (E), Q10.1 (E), R4.2, R5.2, TB1.P1_1 (GND), TB1.P1_2 (GND), TB1.P1_5 (GND), TB1.P1_23 (GND), TB1.P1_49 (GND), TB1.P1_50 (GND), TB1.P2_1 (GND), TB1.P2_2 (GND), TB1.P2_49 (GND), TB1.P2_50 (GND), U1.2 (Input-), U1.4 (OUTPUT-), U2.2 (Input-), U2.4 (OUTPUT-), U3.2 (Input-), U3.4 (OUTPUT-), U9.2 (GND), U11.2 (GND)
BMS_Pin: Q6.3 (C), R19.2, TB1.P2_15 (PE2)
BSPD_Pin: Q8.3 (C), R17.2, TB1.P2_13 (PE4)
CAN1_{RX}: TB1.P2_19 (PB8), U11.4 (CRX)
CAN1_{TX}: TB1.P2_20 (PB9), U11.3 (CTX)
CAN2_{RX}: TB1.P1_36 (PB12), U9.4 (CRX)
CAN2_{TX}: TB1.P1_37 (PB13), U9.3 (CTX)
CAN_H_{BMS}: J4.1, J4.3, J4.7, U11.5 (CANH)
CAN_H_{STR}: J4.5, R3.1, U9.5 (CANH)
CAN_L_{BMS}: J4.2, J4.4, J4.8, U11.6 (CANL)
CAN_L_{STR}: J4.6, R3.2, U9.6 (CANL)
DIST_FL: J2.2, TB1.P1_16 (PA4)
DIST_FR: J2.5, TB1.P1_11 (PA1)
DIST_RL: J1.5, TB1.P1_13 (PA3)
DIST_RR: J1.2, TB1.P1_14 (PA2)
HV_ACTIVE_Pin: Q10.3 (C), R23.2, TB1.P2_17 (PE0)
IMD_Pin: Q7.3 (C), R18.2, TB1.P2_16 (PE3)
unnamed: A1.27 (+5V), R6.1, R7.2
unnamed: A1.2 (D0/RX), R2.2
unnamed: A1.1 (D1/TX), R1.2
unnamed: Q6.2 (B), R16.2
unnamed: Q7.2 (B), R15.2
unnamed: Q8.2 (B), R14.2
unnamed: Q9.2 (B), R20.2
unnamed: Q10.2 (B), R22.2
unnamed: R2.1, R4.1, TB1.P2_29 (PD5)
unnamed: R1.1, R5.1, TB1.P2_30 (PD6)
OK_{BMS}: J3.3, R16.1
OK_{BSPD}: J3.1, R14.1
OK_{HV}: J3.5, R22.1
OK_{IMD}: J3.2, R15.1
OK_{RTD}: J3.4, R20.1
RPi_{RX}: J5.1, TB1.P2_37 (PC10)
RPi_{TX}: J5.2, TB1.P2_38 (PC11)
RTD_ACTIVE_Pin: Q9.3 (C), R21.2, TB1.P2_18 (PE1)
Wh_S_L_5V: A1.20 (A1), J9.1, R7.1
Wh_S_R_5V: A1.19 (A0), J10.1, R6.2

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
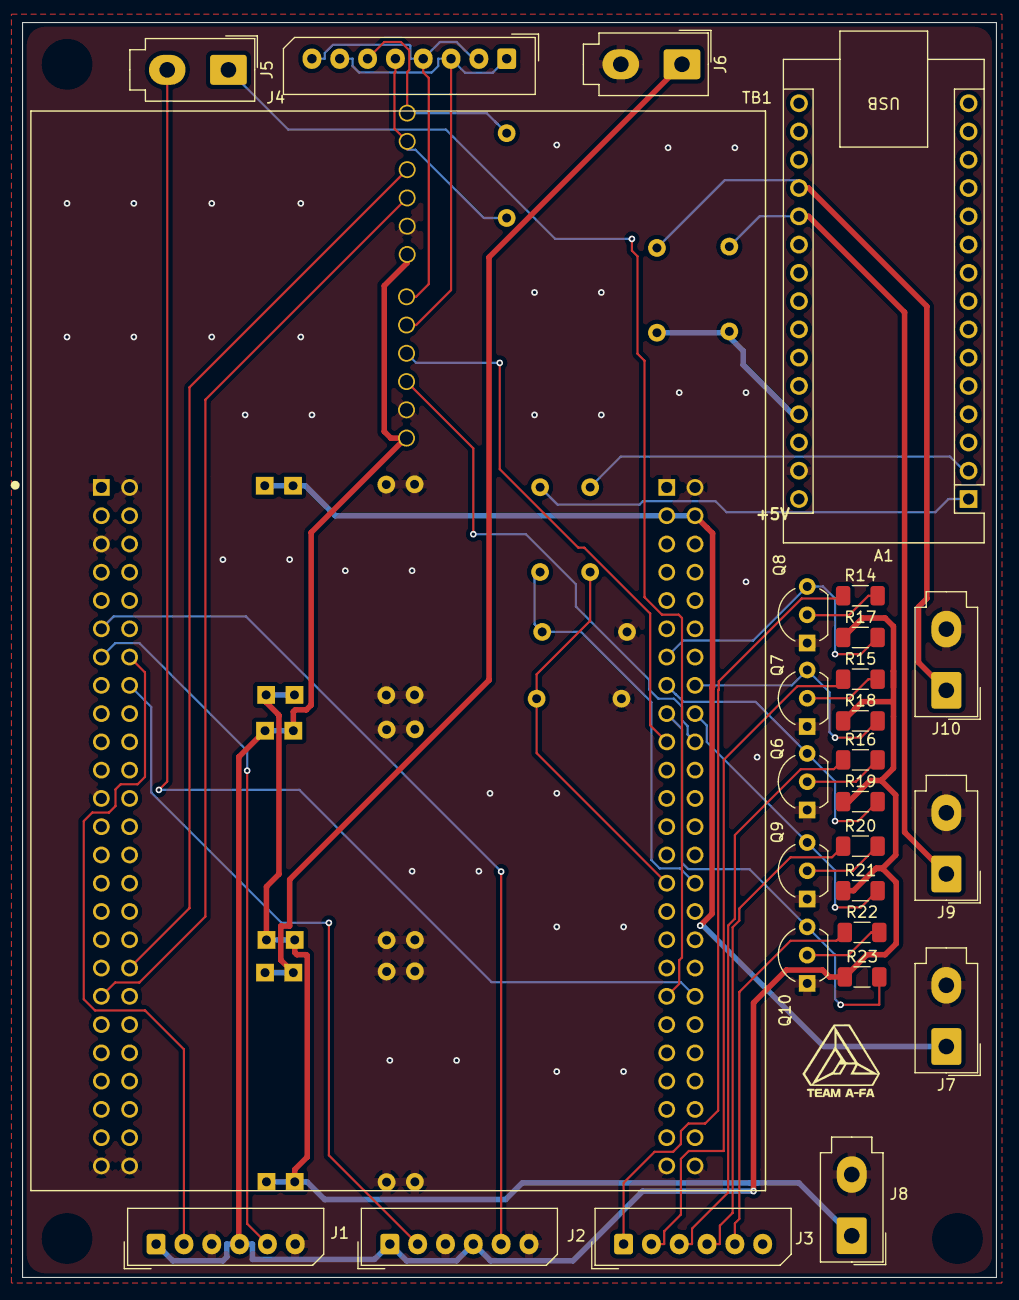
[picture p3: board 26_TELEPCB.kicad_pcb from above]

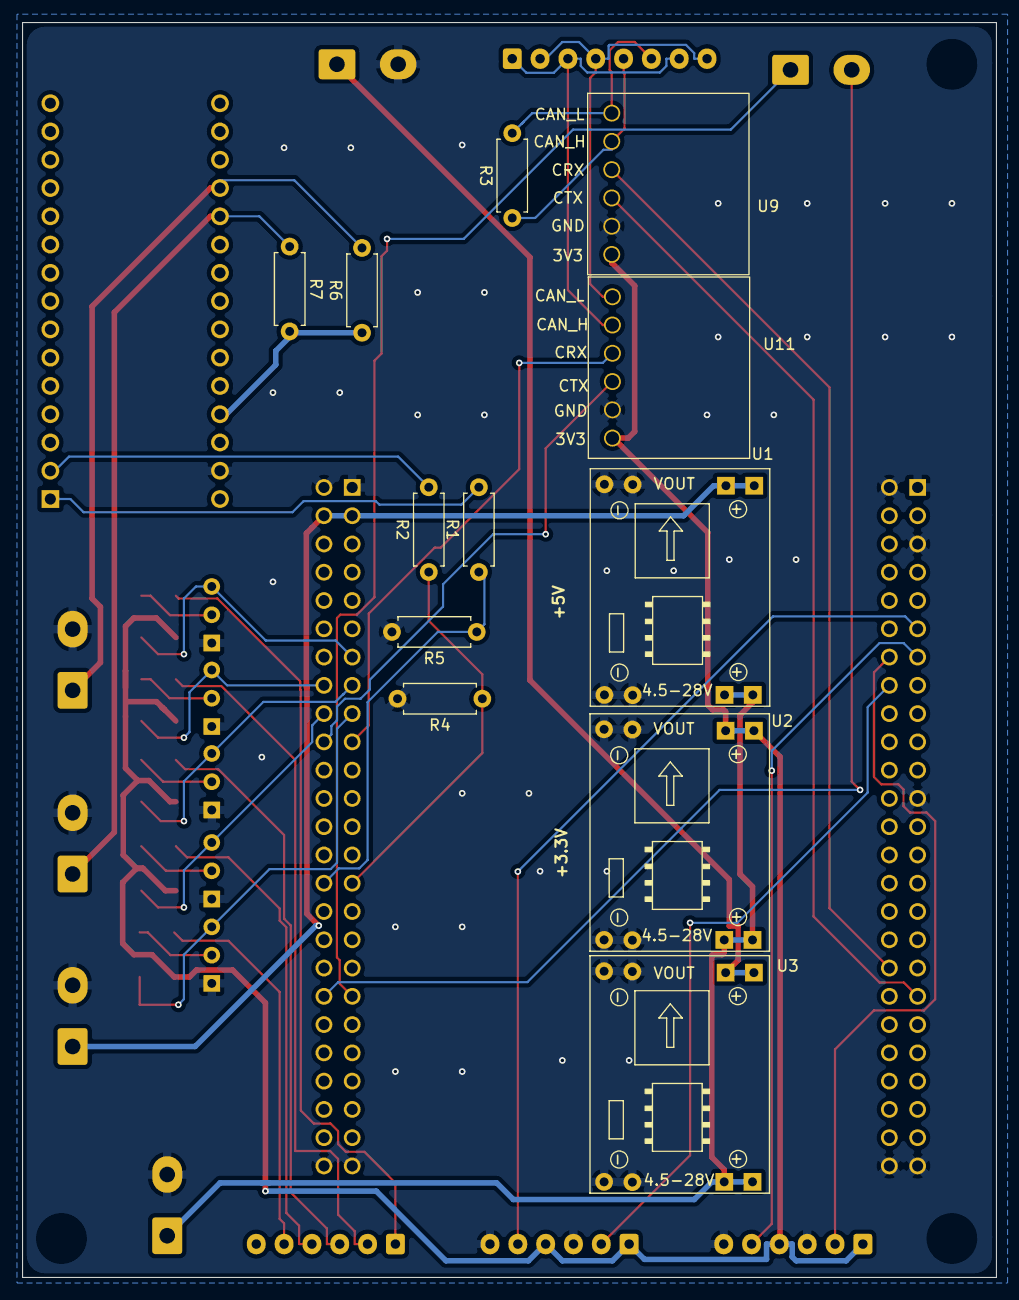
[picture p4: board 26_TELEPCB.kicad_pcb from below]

Board: 2 copper layers, 87.5 x 112.8 mm, 39 parts (12 on the bottom side), 41 nets.

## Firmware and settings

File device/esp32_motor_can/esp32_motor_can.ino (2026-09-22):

/**
 * ESP32 + WC-MCU230 — Cascadia CAN (V5_9)
 * WiFi 없음. 시리얼로 ID별 바이트 위치 + 파싱 값 출력.
 *
 * 배선: 3.3V→VCC | GND→GND | GPIO5→CTX | GPIO4→CRX | CANH/L @ 250kbps
 */

#include <math.h>
#include <string.h>
#include "driver/twai.h"

#define CAN_BITRATE_K  250
#define CAN_TX_GPIO    5
#define CAN_RX_GPIO    4

/* Cascadia V5_9 default offset 0x0A0 */
static const uint32_t ID_0A0 = 0x0A0; /* Temperatures #1 */
static const uint32_t ID_0A2 = 0x0A2; /* Temperatures #3 */
static const uint32_t ID_0A5 = 0x0A5; /* Motor Position */
static const uint32_t ID_0A6 = 0x0A6; /* Current */
static const uint32_t ID_0A7 = 0x0A7; /* Voltage */
static const uint32_t ID_0AA = 0x0AA; /* Internal States */

static const uint32_t PRINT_MS = 500;

struct MotorState {
  float igbt_a_c, igbt_b_c, igbt_c_c;
  float motor_temp_c;
  float rpm;
  float dc_i_a;
  float dc_v_v;
  uint8_t vsm;
  uint8_t inv_state;
  uint8_t precharge;
  uint8_t main_contactor;
  uint8_t run_mode; /* 0=Torque 1=Speed */
  uint8_t raw_0a0[8], raw_0a2[8], raw_0a5[8], raw_0a6[8], raw_0a7[8], raw_0aa[8];
  uint8_t dlc_0a0, dlc_0a2, dlc_0a5, dlc_0a6, dlc_0a7, dlc_0aa;
  uint32_t rx_any, rx_0a0, rx_0a2, rx_0a5, rx_0a6, rx_0a7, rx_0aa;
};

static MotorState g = {};
static uint32_t g_last_print = 0;
static uint32_t g_bus_error = 0;

static int16_t le_i16(const uint8_t *d, uint8_t off)
{
  return (int16_t)((uint16_t)d[off] | ((uint16_t)d[off + 1] << 8));
}

static float x10(const uint8_t *d, uint8_t off)
{
  return (float)le_i16(d, off) * 0.1f;
}

static void save_raw(uint8_t *dst, uint8_t *dlc_out, const uint8_t *src, uint8_t dlc)
{
  memset(dst, 0, 8);
  uint8_t n = (dlc > 8) ? 8 : dlc;
  memcpy(dst, src, n);
  *dlc_out = n;
}

static void update_vsm(uint8_t vsm)
{
  g.vsm = vsm;
  /* PDF: 1=Precharge Init, 2=Precharge Active, 3=Complete, 5=Ready, 6=Running, 7=Fault blink */
  g.precharge = (vsm == 1 || vsm == 2) ? 1 : 0;
  g.main_contactor = (vsm >= 3 && vsm <= 6) ? 1 : 0;
}

static float igbt_max()
{
  float m = g.igbt_a_c;
  if (g.igbt_b_c > m) m = g.igbt_b_c;
  if (g.igbt_c_c > m) m = g.igbt_c_c;
  return m;
}

/*
 * Cascadia V5_9 Little-Endian:
 *  Temperature / Current / High Voltage = int16 * 0.1
 *  Motor Speed (RPM) = int16 * 1
 */
static void parse_known(uint32_t id, const uint8_t *data, uint8_t dlc)
{
  switch (id) {
    case ID_0A0:
      /* B0-1 IGBT A, B2-3 IGBT B, B4-5 IGBT C, B6-7 GateDriver  (°C×10) */
      save_raw(g.raw_0a0, &g.dlc_0a0, data, dlc);
      if (dlc >= 2) g.igbt_a_c = x10(data, 0);
      if (dlc >= 4) g.igbt_b_c = x10(data, 2);
      if (dlc >= 6) g.igbt_c_c = x10(data, 4);
      g.rx_0a0++;
      break;

    case ID_0A2:
      /* B0-1 Coolant, B2-3 Hotspot, B4-5 MotorTemp (°C×10), B6-7 TorqueShudder */
      save_raw(g.raw_0a2, &g.dlc_0a2, data, dlc);
      if (dlc >= 6) g.motor_temp_c = x10(data, 4);
      g.rx_0a2++;
      break;

    case ID_0A5:
      /* B0-1 MotorAngle(°×10), B2-3 MotorSpeed(RPM), B4-5 ElecFreq(Hz×10) */
      save_raw(g.raw_0a5, &g.dlc_0a5, data, dlc);
      if (dlc >= 4) g.rpm = (float)le_i16(data, 2);
      g.rx_0a5++;
      break;

    case ID_0A6:
      /* B0-1 PhA, B2-3 PhB, B4-5 PhC, B6-7 DC Bus Current (A×10) */
      save_raw(g.raw_0a6, &g.dlc_0a6, data, dlc);
      if (dlc >= 8) g.dc_i_a = x10(data, 6);
      g.rx_0a6++;
      break;

    case ID_0A7:
      /* B0-1 DC Bus V (V×10), B2-3 Output V, B4-5 VAB/Vd, B6-7 VBC/Vq */
      save_raw(g.raw_0a7, &g.dlc_0a7, data, dlc);
      if (dlc >= 2) g.dc_v_v = x10(data, 0);
      g.rx_0a7++;
      break;

    case ID_0AA:
      /* B0 VSM, B2 InverterState, B4 bit0 RunMode(0=Trq/1=Spd) */
      save_raw(g.raw_0aa, &g.dlc_0aa, data, dlc);
      if (dlc >= 1) update_vsm(data[0]);
      if (dlc >= 3) g.inv_state = data[2];
      if (dlc >= 5) g.run_mode = (uint8_t)(data[4] & 0x01);
      g.rx_0aa++;
      break;

    default:
      break;
  }
}

static void print_bytes(const char *label, const uint8_t *raw, uint8_t dlc)
{
  Serial.printf("  %-10s raw[%u]=", label, dlc);
  for (uint8_t i = 0; i < dlc; i++) Serial.printf("%02X ", raw[i]);
  if (dlc == 0) Serial.print("(no rx yet)");
  Serial.println();
}

static bool can_init()
{
  twai_general_config_t gcfg = TWAI_GENERAL_CONFIG_DEFAULT(
      (gpio_num_t)CAN_TX_GPIO, (gpio_num_t)CAN_RX_GPIO, TWAI_MODE_NORMAL);
  twai_timing_config_t tcfg = TWAI_TIMING_CONFIG_250KBITS();
  twai_filter_config_t fcfg = TWAI_FILTER_CONFIG_ACCEPT_ALL();

  if (twai_driver_install(&gcfg, &tcfg, &fcfg) != ESP_OK) return false;
  if (twai_start() != ESP_OK) return false;

  twai_reconfigure_alerts(
      TWAI_ALERT_RX_DATA | TWAI_ALERT_BUS_ERROR | TWAI_ALERT_RX_QUEUE_FULL, NULL);

  Serial.printf("[can] NORMAL %dkbps TX=GPIO%d RX=GPIO%d\n",
                CAN_BITRATE_K, CAN_TX_GPIO, CAN_RX_GPIO);
  return true;
}

static void can_poll()
{
  uint32_t alerts = 0;
  if (twai_read_alerts(&alerts, 0) == ESP_OK) {
    if (alerts & TWAI_ALERT_BUS_ERROR) g_bus_error++;
  }

  twai_message_t msg;
  while (twai_receive(&msg, 0) == ESP_OK) {
    if (msg.extd || msg.rtr) continue;
    g.rx_any++;
    parse_known(msg.identifier, msg.data, msg.data_length_code);
  }
}

static void print_byte_map()
{
  Serial.println();
  Serial.println("======== Cascadia V5_9 바이트 맵 (LE) ========");
  Serial.println("ID   | Bytes | 필드              | 스케일");
  Serial.println("-----+-------+-------------------+--------------");
  Serial.println("0xA0 | 0-1   | IGBT Module A     | C x10");
  Serial.println("0xA0 | 2-3   | IGBT Module B     | C x10");
  Serial.println("0xA0 | 4-5   | IGBT Module C     | C x10");
  Serial.println("0xA0 | 6-7   | Gate Driver Temp  | C x10");
  Serial.println("0xA2 | 0-1   | Coolant           | C x10");
  Serial.println("0xA2 | 2-3   | Hot Spot          | C x10");
  Serial.println("0xA2 | 4-5   | Motor Temp   [*]  | C x10");
  Serial.println("0xA5 | 0-1   | Motor Angle       | deg x10");
  Serial.println("0xA5 | 2-3   | Motor Speed  [*]  | RPM x1");
  Serial.println("0xA5 | 4-5   | Electrical Freq   | Hz x10");
  Serial.println("0xA6 | 0-1   | Phase A Current   | A x10");
  Serial.println("0xA6 | 2-3   | Phase B Current   | A x10");
  Serial.println("0xA6 | 4-5   | Phase C Current   | A x10");
  Serial.println("0xA6 | 6-7   | DC Bus Current[*] | A x10");
  Serial.println("0xA7 | 0-1   | DC Bus Voltage[*] | V x10");
  Serial.println("0xA7 | 2-3   | Output Voltage    | V x10");
  Serial.println("0xAA | 0     | VSM State         | enum");
  Serial.println("0xAA | 2     | Inverter State    | enum");
  Serial.println("0xAA | 4.0   | Run Mode     [*]  | 0=Trq 1=Spd");
  Serial.println("[*] = 우리가 로그/서버에 쓰는 값");
  Serial.println("==============================================");
  Serial.println();
}

static void print_status()
{
  Serial.println("---------- 파싱 결과 (바이트 → 값) ----------");

  print_bytes("0xA0", g.raw_0a0, g.dlc_0a0);
  Serial.printf("       B0-1 IGBT_A=%.1fC  B2-3 IGBT_B=%.1fC  B4-5 IGBT_C=%.1fC  max=%.1fC\n",
                g.igbt_a_c, g.igbt_b_c, g.igbt_c_c, igbt_max());

  print_bytes("0xA2", g.raw_0a2, g.dlc_0a2);
  Serial.printf("       B4-5 MotorTemp=%.1fC\n", g.motor_temp_c);

  print_bytes("0xA5", g.raw_0a5, g.dlc_0a5);
  Serial.printf("       B2-3 RPM=%.0f\n", g.rpm);

  print_bytes("0xA6", g.raw_0a6, g.dlc_0a6);
  Serial.printf("       B6-7 DC_Current=%.1fA\n", g.dc_i_a);

  print_bytes("0xA7", g.raw_0a7, g.dlc_0a7);
  Serial.printf("       B0-1 DC_Voltage=%.1fV\n", g.dc_v_v);

  print_bytes("0xAA", g.raw_0aa, g.dlc_0aa);
  Serial.printf("       B0 VSM=%u  B2 InvState=%u  B4bit0 Mode=%u(%s)  pre=%u mc=%u\n",
                (unsigned)g.vsm, (unsigned)g.inv_state,
                (unsigned)g.run_mode, g.run_mode ? "Speed" : "Torque",
                (unsigned)g.precharge, (unsigned)g.main_contactor);

  Serial.printf("rx ANY=%lu | A0=%lu A2=%lu A5=%lu A6=%lu A7=%lu AA=%lu | bus_err=%lu\n",
                (unsigned long)g.rx_any,
                (unsigned long)g.rx_0a0, (unsigned long)g.rx_0a2, (unsigned long)g.rx_0a5,
                (unsigned long)g.rx_0a6, (unsigned long)g.rx_0a7, (unsigned long)g.rx_0aa,
                (unsigned long)g_bus_error);
  if (g.rx_any == 0) {
    Serial.println("!! 수신 0 — TX/RX 교차 또는 ACK/배선 확인");
  }
  Serial.println();
}

void setup()
{
  Serial.begin(115200);
  delay(500);
  Serial.println();
  Serial.println("=== ESP32 Cascadia CAN byte-map parse ===");
  print_byte_map();
  if (!can_init()) Serial.println("[fatal] CAN init fail");
  g_last_print = millis();
}

void loop()
{
  can_poll();
  uint32_t now = millis();
  if (now - g_last_print >= PRINT_MS) {
    g_last_print = now;
    print_status();
  }
}

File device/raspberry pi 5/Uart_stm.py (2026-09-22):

"""
STM32(UART4, 921600) -> Raspberry Pi 5 GPIO UART 수신

하드웨어 (40핀 GPIO):
  Pi Pin 8  (GPIO14 TXD) -> STM32 UART4 RX (PC11)
  Pi Pin 10 (GPIO15 RXD) -> STM32 UART4 TX (PC10)
  Pi GND (Pin 6 등)     -> STM32 GND
  소프트웨어 포트: /dev/ttyAMA0 (Pi5 GPIO Pin 8/10, dtparam=uart0=on)

  주의: Pi5 에서 /dev/serial0 은 ttyAMA10(보드 옆 3핀 UART)일 수 있음.
        GPIO 8/10 배선이면 반드시 /dev/ttyAMA0 사용.

- 100 Hz: FR, FL, RR, RL, x_g, y_g, z_g + timestamp 를 data[] 에 적재
- 20 Hz(50 ms): data[] 를 배치로 넘긴 뒤 초기화

STM32 한 줄 형식 (CSV, \\n 종료):
  FR,FL,RR,RL,x_g,y_g,z_g
또는 STM32 타임스탬프(ms) + MCU 칩 내부 온도 + LWS 조향 + 핵심 CAN(BMS/인버터) 포함:
  stm_ms,FR,FL,RR,RL,x_g,y_g,z_g,ecu_temp,steering_angle,steering_speed,
  inv_temp_igt,inv_temp_motor,inv_motor_speed,inv_dc_current,inv_voltage,
  motor_precharge,motor_main_contactor,motor_inverter_mode(0=Torque,1=Speed),
  inv_shudder_torque,inv_id_feedback,inv_iq_feedback,
  inv_torque_commanded,inv_torque_feedback,inv_id_command,inv_iq_command,
  bms_charge,bms_voltage,bms_current,bms_ccl,bms_dcl,bms_temp_maxvalue,bms_capacity,
  can1,can2
"""

from __future__ import annotations

import argparse
import os
import sys
import threading
import time
from pathlib import Path
from typing import Any, Callable

try:
    import serial
    from serial.tools import list_ports
except ImportError:
    print("[error] pyserial 이 필요합니다.  pip install pyserial")
    sys.exit(1)


class UartOpenError(RuntimeError):
    """UART 포트를 열지 못했을 때 (자동 재시도용)."""


DEFAULT_BAUD = 921600
DEFAULT_UART_PORT = "auto"
UART_MODULE_VERSION = "2026-07-28-uart921k"

# Pi5 GPIO Pin 8/10 (GPIO14/15). dtparam=uart0=on 필요.
GPIO_UART_DEVICE = "/dev/ttyAMA0"

# 구버전 스크립트 기본값. 장치가 없으면 auto 로 처리.
LEGACY_UART_PORTS = frozenset({"/dev/ttyAMA0", "ttyAMA0"})

# auto 탐색 순서. ttyS0 는 GPIO 8/10 이 아님 — 제외.
PI_UART_CANDIDATES = (
    "/dev/ttyAMA0",
    "/dev/serial0",
    "/dev/ttyAMA10",
    "/dev/ttyUSB0",
    "/dev/ttyACM0",
)

SAMPLE_RATE_HZ = 100
FLUSH_RATE_HZ = 20
FLUSH_INTERVAL_S = 1.0 / FLUSH_RATE_HZ
SAMPLES_PER_BATCH = SAMPLE_RATE_HZ // FLUSH_RATE_HZ  # 5

LINEAR_KEYS = ("FR", "FL", "RR", "RL")
ACCEL_KEYS = ("x_g", "y_g", "z_g")
ECU_TEMP_KEY = "ecu_temp"
STEERING_KEYS = ("steering_angle", "steering_speed")
CAN_INV_KEYS = (
    "inv_temp_igt",
    "inv_temp_motor",
    "inv_motor_speed",
    "inv_dc_current",
    "inv_voltage",
)
CAN_MOTOR_STATUS_KEYS = (
    "motor_precharge",
    "motor_main_contactor",
    "motor_inverter_mode",
)
CAN_INV_TORQUE_KEYS = (
    "inv_shudder_torque",
    "inv_id_feedback",
    "inv_iq_feedback",
    "inv_torque_commanded",
    "inv_torque_feedback",
    "inv_id_command",
    "inv_iq_command",
)
CAN_BMS_KEYS = (
    "bms_charge",
    "bms_voltage",
    "bms_current",
    "bms_ccl",
    "bms_dcl",
    "bms_temp_maxvalue",
    "bms_capacity",
)
CAN_LINK_KEYS = (
    "can1",
    "can2",
)
SENSOR_KEYS = (
    LINEAR_KEYS
    + ACCEL_KEYS
    + (ECU_TEMP_KEY,)
    + STEERING_KEYS
    + CAN_INV_KEYS
    + CAN_MOTOR_STATUS_KEYS
    + CAN_INV_TORQUE_KEYS
    + CAN_BMS_KEYS
    + CAN_LINK_KEYS
)
LEGACY_SENSOR_KEYS = LINEAR_KEYS + ACCEL_KEYS
SENSOR_KEYS_WITH_TEMP = LINEAR_KEYS + ACCEL_KEYS + (ECU_TEMP_KEY,)
SENSOR_KEYS_WITH_STEERING = SENSOR_KEYS_WITH_TEMP + STEERING_KEYS
BOOT_LINE_PREFIXES = ("STM_", "HB,", "LWS_CAL")

# 수신 버퍼 (20 Hz 마다 초기화)
data: list[dict[str, Any]] = []
_data_lock = threading.Lock()
_uart_debug = False


class UartRxStats:
    def __init__(self) -> None:
        self._lock = threading.Lock()
        self.raw_bytes = 0
        self.raw_lines = 0
        self.parsed_samples = 0
        self.parse_errors = 0
        self.last_raw_line = ""
        self.last_bad_line = ""

    def on_bytes(self, nbytes: int) -> None:
        with self._lock:
            self.raw_bytes += nbytes

    def on_line(self, line: str, sample: dict[str, Any] | None) -> None:
        with self._lock:
            self.raw_lines += 1
            self.last_raw_line = line[:120]
            if sample is None:
                if line.strip():
                    self.parse_errors += 1
                    self.last_bad_line = line[:120]
            else:
                self.parsed_samples += 1

    def on_boot_line(self, line: str) -> None:
        with self._lock:
            self.raw_lines += 1
            self.last_raw_line = line[:120]

    def snapshot(self) -> dict[str, Any]:
        with self._lock:
            return {
                "raw_bytes": self.raw_bytes,
                "raw_lines": self.raw_lines,
                "parsed_samples": self.parsed_samples,
                "parse_errors": self.parse_errors,
                "last_raw_line": self.last_raw_line,
                "last_bad_line": self.last_bad_line,
            }


uart_stats = UartRxStats()


def set_uart_debug(enabled: bool) -> None:
    global _uart_debug
    _uart_debug = enabled


def _path_exists(path: str) -> bool:
    try:
        return Path(path).exists()
    except OSError:
        return False


def list_available_uart_ports() -> list[str]:
    found: list[str] = []
    for path in PI_UART_CANDIDATES:
        if _path_exists(path) and path not in found:
            found.append(path)
    try:
        for info in list_ports.comports():
            if info.device not in found:
                found.append(info.device)
    except Exception:
        pass
    return found


def _device_realpath(path: str) -> str:
    try:
        return os.path.realpath(path)
    except OSError:
        return ""


def is_pi5_header_uart(path: str) -> bool:
    return _device_realpath(path).endswith("ttyAMA10")


def print_pi5_gpio_uart_warning(path: str) -> None:
    if not is_pi5_header_uart(path):
        return
    print("[error] /dev/serial0 -> ttyAMA10 = Pi5 보드 옆 3핀 UART 입니다.")
    print("        GPIO Pin 8/10 과는 다른 포트라 루프백/STM 수신이 안 됩니다.")
    print("[fix] /boot/firmware/config.txt 맨 아래 추가 후 reboot:")
    print("        enable_uart=1")
    print("        dtparam=uart0=on")
    print("        dtoverlay=disable-bt")
    print("[fix] 재부팅 후 확인:")
    print("        ls -l /dev/ttyAMA0")
    print("        python uart_test.py --port /dev/ttyAMA0 --loopback")
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

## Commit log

2026-06-25 STM32 ECU, Pi UART ingest, and server logging/realtime pipeline.
    Add ECU_test firmware (LWS CAN, ADC, LIS3DSH, UART batch), Raspberry Pi data_send_server, and sever app/realtime servers with steering support.
2026-06-29 Add dual wheel speed sensing and extend telemetry pipeline.
    Arduino reads A0/A1 pulse counts, STM32 computes left/right RPM and streams to Pi, and server/realtime ingest the new fields. Also adds camera server UI, ffmpeg install script, and removes unused I2C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
2026-07-07 Restructure server services and add CAN vehicle ingestion scaffolding.
    Split logging/realtime services under server/, update STM32 CAN handling for vehicle bus parsing, and include related Raspberry Pi and wheel-speed integration updates.
2026-09-22 Document device architecture and sync STM/Pi telemetry firmware.
    Add a detailed root README covering hardware pin maps, MCU-centric design, UART/CAN pipeline, and linear calibration, and commit the corresponding device source updates without build artifacts.
2026-09-22 Clarify MCU choice is for time sync, not STM lock-in.
    Document that Teensy or other MCUs can replace STM32F407 if ADC, CAN, and a shared timestamp pipeline are preserved.
2026-09-22 Document alternate telemetry paths including E220 LoRa UART modules.
    Compare commercial loggers, this project's Wi-Fi/Hotspot pipeline, and EBYTE E220-900T22S-style wireless serial links without naming other teams.
2026-09-30 Document unresolved issue with ADC sensor power drop
    Added unresolved issue regarding ADC sensor power drop and calibration concerns.
2026-10-06 Add 26_TELEPCB KiCad schematic/PCB
    [26_TELEPCB-B_Cu.gbr, 26_TELEPCB-B_Mask.gbr, 26_TELEPCB-B_Paste.gbr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]
2026-10-06 Clean up repo for public portfolio
    - Add project summary, results, and open issues to README
    - Stop tracking STM32 Debug build outputs and __pycache__ (already in .gitignore)
    - Remove *.bak_restore backup files
    - Replace hard-coded server IP with placeholders; env.ingest -> env.ingest.example
    - Make camera upload URL configurable via CAMERA_URL
    Claude-Session: https://claude.ai/code/session_01SC5BrPGA5v7GiQyYeWZoPx
    [camera.py, data_send_server.py]
